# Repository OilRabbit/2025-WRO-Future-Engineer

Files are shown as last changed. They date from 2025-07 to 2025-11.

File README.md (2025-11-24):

# Welcome to the GitHub Repository of Team Evo1ution for 2025 WRO Future Engineering 

## Links

[About Our Team](#about-our-team)

[Documentation](documentation/WROFEReport.pdf)

[Meeting Agenda & Minutes](https://docs.google.com/document/d/1UcRYFaWVR6Crpbr7qZHQyp-bxXoaFOH1-K7Gqp4DvTU/edit?usp=sharing)

[Pictures and Practice Videos](picsNveds)

[Practice Videos](picsNveds/videos_link.md)

[Our Code](https://github.com/OilRabbit/2025-WRO-Future-Engineer/tree/Gen-6.0_ESP32/main)

[Wiring Diagram](https://github.com/OilRabbit/2025-WRO-Future-Engineer/tree/Gen-6.0_ESP32/wiring)

## About Our Team

Our team is comprised of five Po Leung Kuk Tang Yuk Tien College alumni, each a former Robotics Team chairperson. Through years of competitions and training, we forged strong friendships and a shared passion for robotics. As avid World Robot Olympiad (WRO) supporters, we were excited to learn that the Future Engineer category age limit increased to 22 in 2025. In January, during a casual meetup, we resolved to reunite and compete together once again.

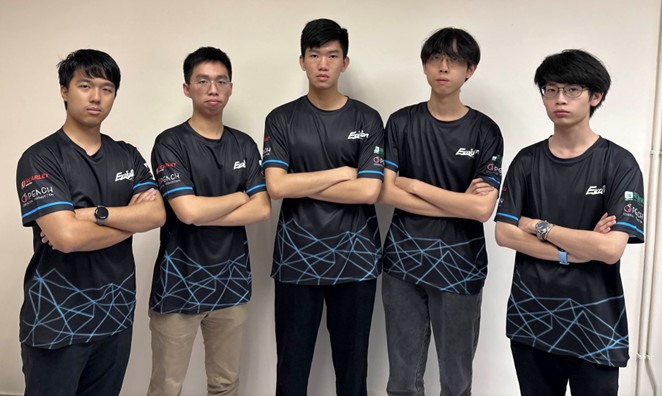
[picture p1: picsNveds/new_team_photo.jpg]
team_photo

### Members' Introductions (from left to right)

#### Rex Sin (Participant) – Age 19
Rex is studying Computer Science in Australia, but remains fully engaged in our team via video conferencing. He leads strategy design, debugging, and solution development, produces and uploads our YouTube videos, and co-ordinates this report. He began robotics at age 12 and won the U.S. Robot Parade world championship represent-ing Hong Kong, later earning numerous local competition awards.

#### Donald Tong (Participant) – Age 19
Donald, a Civil and Environmental Engineering student and PLKTYTC Robotics Team coach, develops core li-braries and functions, fine-tunes robot behavior, and conducts extensive operational tests, such as evaluating var-ied object placements. He and Rex Sin earned second place in the 2024 WRO Hong Kong Senior Robomission selection, and he previously placed second in the 2019 international Beach Rescue and Salvage Robot contests.

#### Elwin Li (Coach) – Age 22
Elwin is an MPhil Physics student who previously coached the PLKTYTC Robotics Team and Physics Olympiad class. With expertise in physics, mathematics, and programming, he contributes to university research on gravita-tional waves. In our team, he directs meeting planning, goal setting, task assignment, sponsorship coordination, hardware procurement, and, most critically, programming strategy. Elwin also competed in the 2021 Robocon Hong Kong Contest and served as a judge for the 2024 WRO Hong Kong Future Engineer selection.

#### Harrison Tsang (Participant) – Age 20
Studying Artificial Intelligence: Systems and Technologies, Harrison coaches the PLKTYTC Robotics Team and leads our robot construction and primary program development. While preparing concurrently for the 2025 Ro-bocon Hong Kong Contest, he brought experience as the 2021 WRO Hong Kong Senior RoboMission champion and multiple world-title winner in international robotics that year.

#### Harold Cheung (Supporter) – Age 23
Harold is a final-year Aeronautical and Aviation Engineering student and former PLKTYTC Robotics Team coach, specializing in mechanical design and robot structures. In our team, he delivers vehicle fundamentals training, oversees mechanical design, advises on sensor integration and strategy, and assists with component procure-ment. A motorsport enthusiast and amateur go-kart racer, Harold has competed alongside Elwin in robotics con-tests for over ten years, even leveraging insights from his personal kart to inform our robot’s design.

----

## Our design for the Hong Kong Regional Copetition
During the WRO Hong Kong Regional Competition, we selected the MATRIX Mini R4 controller and some of its official motors and sensors. We believed that they should work well together to maximise the overall performance as they are all MATRIX electrical components. The chassis was built with LEGO and MATRIX components assisted with screwes to hold the electrical components. 

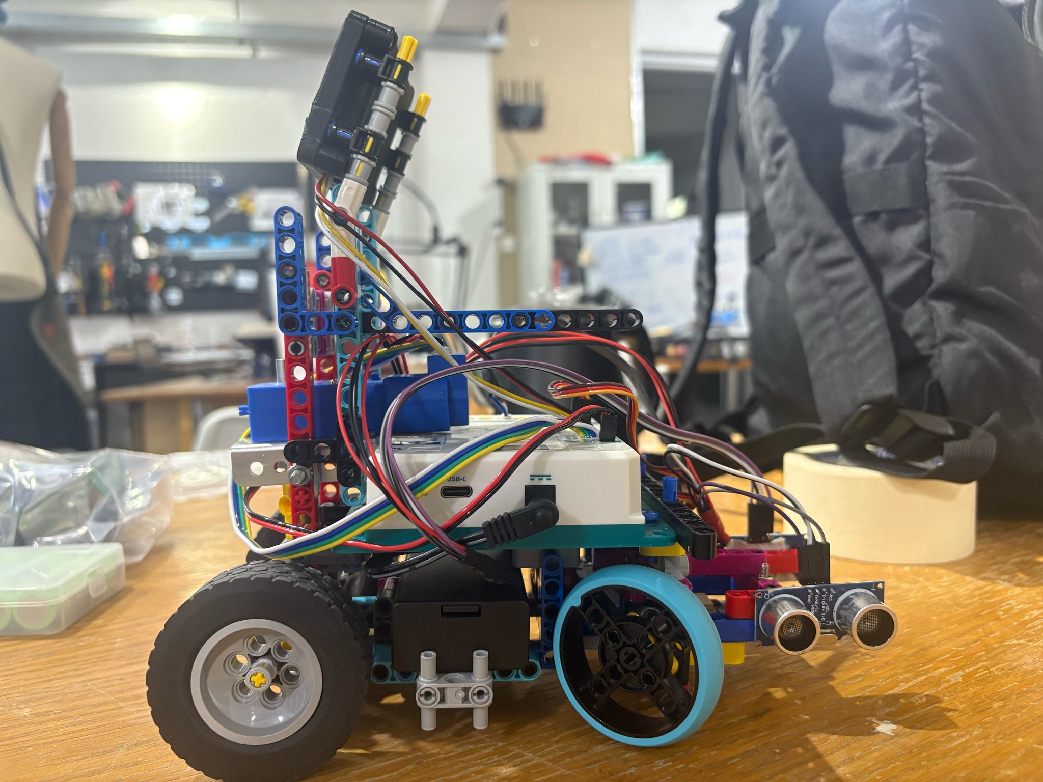
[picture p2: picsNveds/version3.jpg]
version3


However, we found that the MATRIX controller has a high latency when handling multiple tasks and an unstable IMU sensor. These problems increased the diffculty of tuning the program because of errors caused by them. Thus, we decided to replace those electrical components with better models.

----

## Our current design

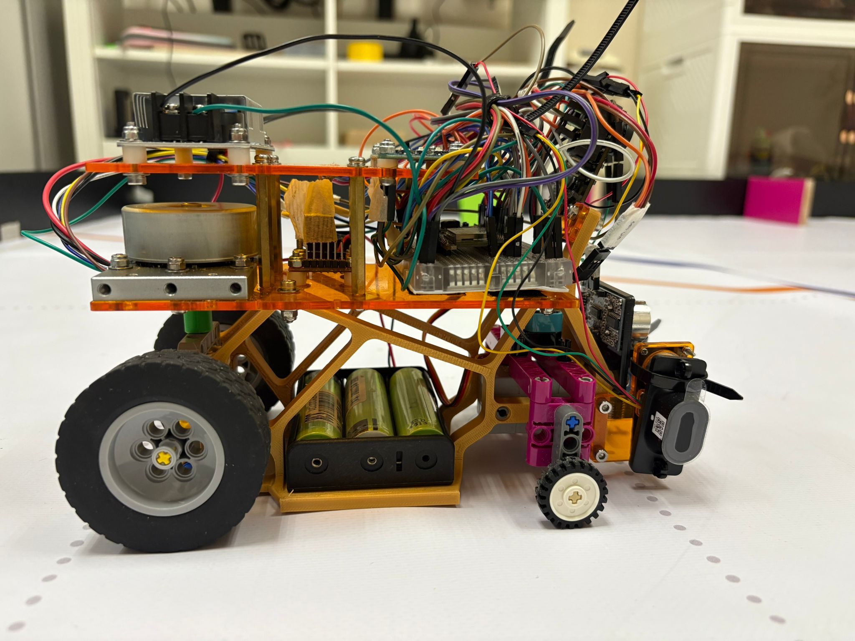
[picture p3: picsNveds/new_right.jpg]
new_right


After doing some research about controllers that are often used in such competitions, we decided to separate into two sub-teams to work on EV3 and ESP32 separately. Despite the fact that EV3 has several limitations on both hardware and software, we still gave it a try, as we are all familiar with it. As a result, it has much higher stability than the MATRIX robot. However, the problem of gyro drift is critical, and the robot does not move fast enough. Meanwhile, we found that the ESP32 features multi-threading and powerful computing. From the result of testing the processing power of the ESP32 by replacing the MATRIX controller with the ESP32 while other electronic components remain the same, it showed its excellent performance and stability. Thus, we decided to work further on ESP32.

To further enhance performance, we replaced the MATRIX motor with the BM50 brushless motor with an encoder for the drive, which in-creases speed. It offers additional stability, acting like a gyroscope while in operation, and features a built-in en-coder for precise power control. Regarding the problematic sensors, we changed a better IMU (ICM-20948) and camera (PixyCam2.1). It is worth mentioning that the ultrasonic sensors were replaced by ToF sensors due to the fast measuring rate and high accuracy of ToF sensors.

----

## How do we work together
As a current college students, we need to balance our studies, works, and the preperation for this competition. Although our spare time do not collide much, we spent as much time as possible working on this project. Even though sometimes we need to work alone. By the way, thank to our coach and supporter for taking time from their busy schedule to come to our working place to give advises. We used GitHub to share code and log our work. We communicate through a WhatsApp group and have a short call with Rex regularly to update him about the condition for the documentations and strategy designs.

----

## What we learnt
* Slip angle optimisation is unnecessary for our small robot, the Ackermann effect is minimal, though we demonstrated a simple LEGO implementation regardless.
* A differential is essential: it significantly smooths turning at low speeds despite a slight reduction in straight‐line velocity.
* A shorter wheelbase enhances turning fluidity.
* A wider track during turns, greater spacing between front wheels than rear, improves cornering smooth-ness (we omitted this due to chassis‐width constraints).
* Lightweight wheels markedly increase top speed more than reducing overall vehicle mass.
* Smaller wheel diameters boost manoeuvrability.
* A low centre of mass enhances stability.
* An onboard gyro provides precise heading data and lap counting.
* Storing pillar colours in an array on the first detection enables faster reaction on subsequent passes.
* Reducing camera resolution (where feasible) increases frame rate and responsiveness.

----

## Conclusion
This is a really challenging project as this is our first time using those hardware and there are so many things need to learn for this. We enjoy the process of searching through the field we love and learning something new. We believe that what we learnt from this competition is more valuable than the result.

----

## Special thanks
Our sponsors:

| [Peach Creatice Production](https://www.peachcp.com/wp/) | [TURNED-E!](https://www.turned-e.com/) | [Scarlet Racing](https://www.facebook.com/scarlet.racing.hk/?locale=zh_HK) | Electronic Slash |
| --- | --- | --- | --- |
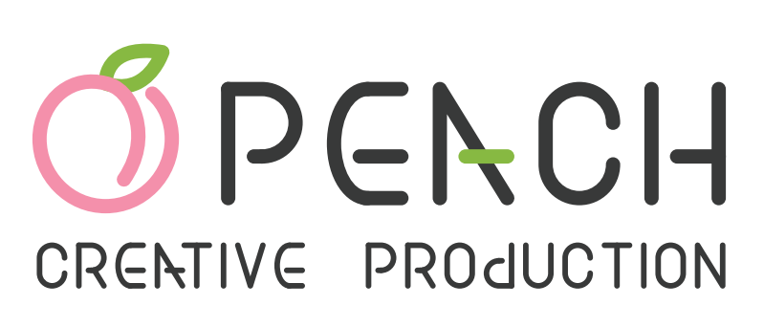
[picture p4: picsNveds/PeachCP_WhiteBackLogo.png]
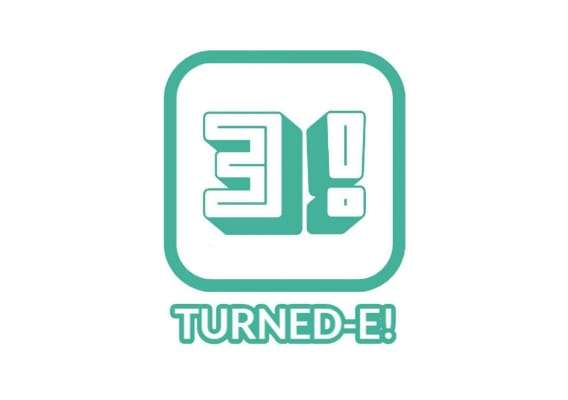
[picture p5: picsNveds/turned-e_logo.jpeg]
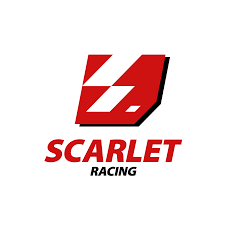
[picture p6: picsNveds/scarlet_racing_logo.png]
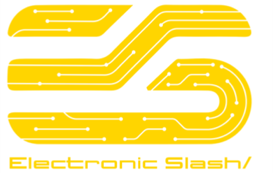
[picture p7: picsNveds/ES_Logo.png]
|||||

Also thank to our parents, coach and supporter for supporting us to explore the field we love.

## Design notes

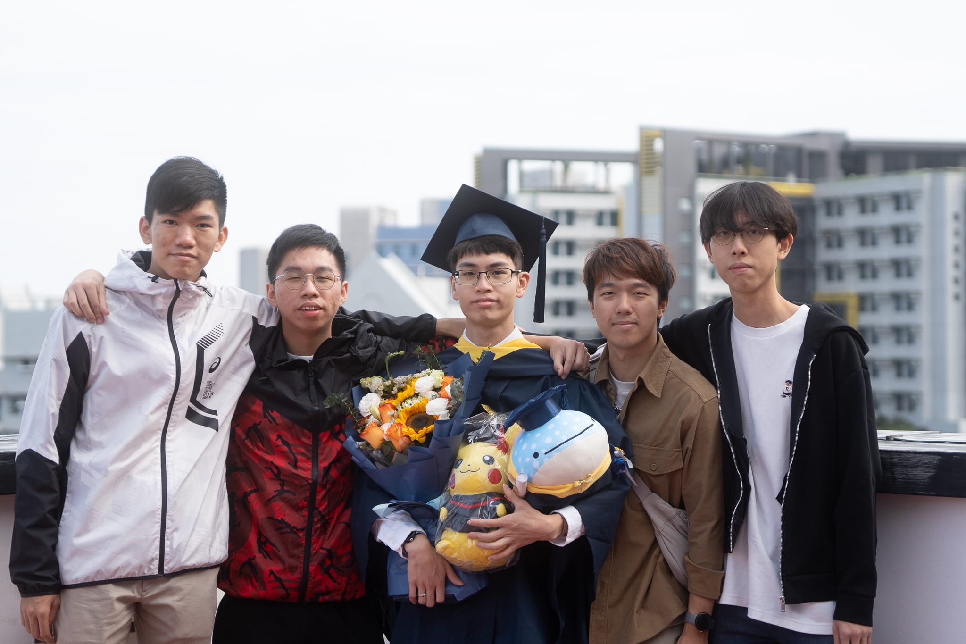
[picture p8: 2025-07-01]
picsNveds/team_photo13.jpeg

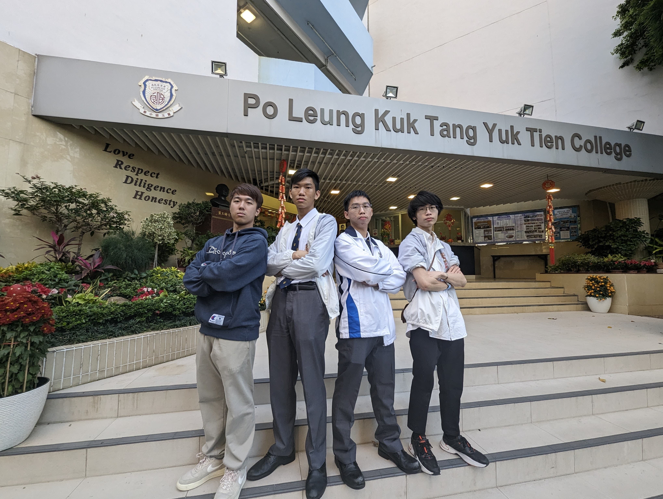
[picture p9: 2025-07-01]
picsNveds/team_photo7.jpeg

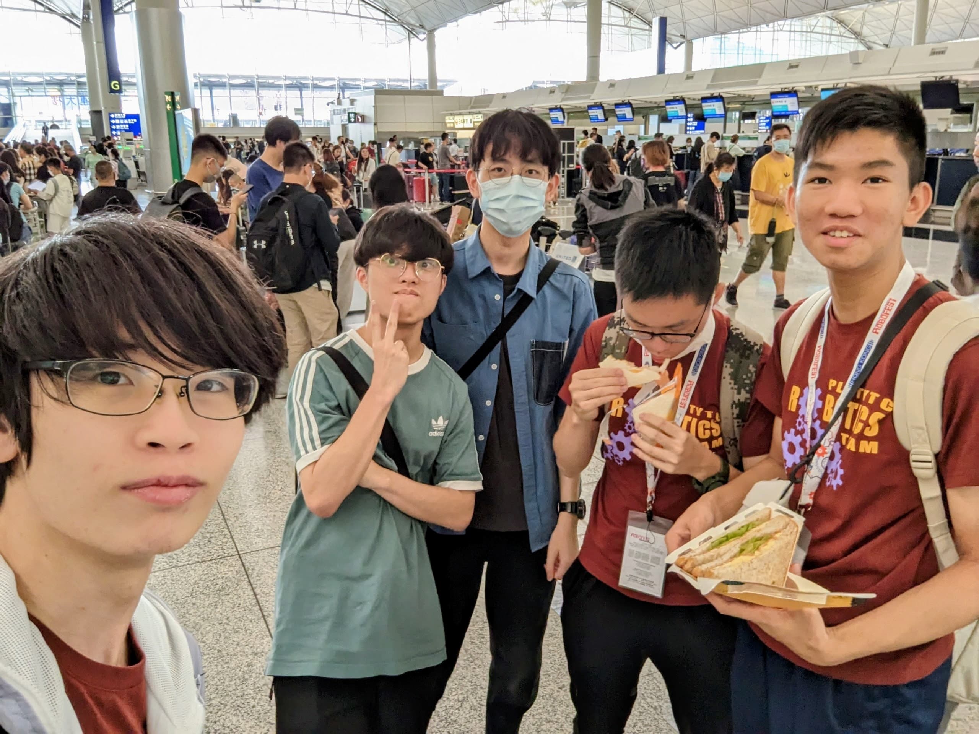
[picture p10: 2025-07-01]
picsNveds/team_photo15.jpeg

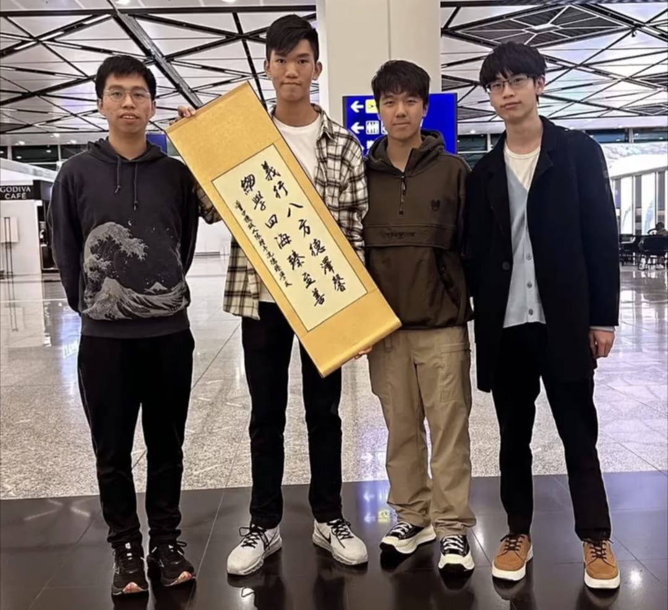
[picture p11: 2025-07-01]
picsNveds/team_photo12.jpeg

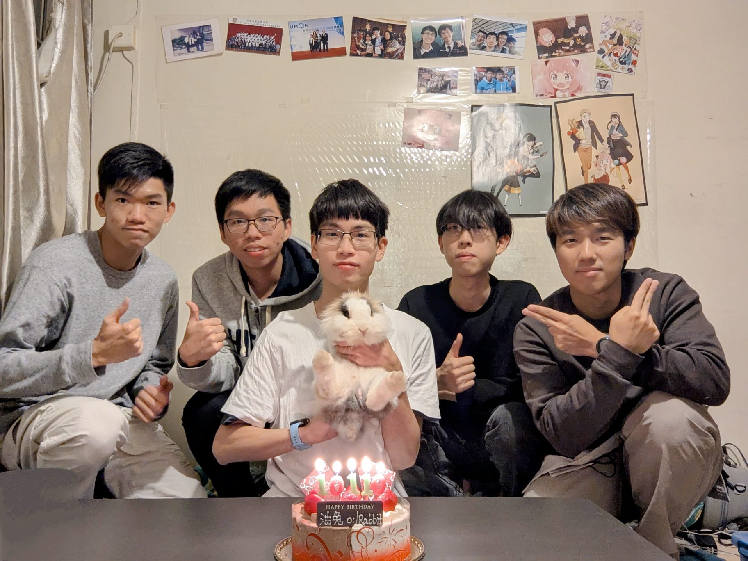
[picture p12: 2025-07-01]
picsNveds/team_photo2.jpeg

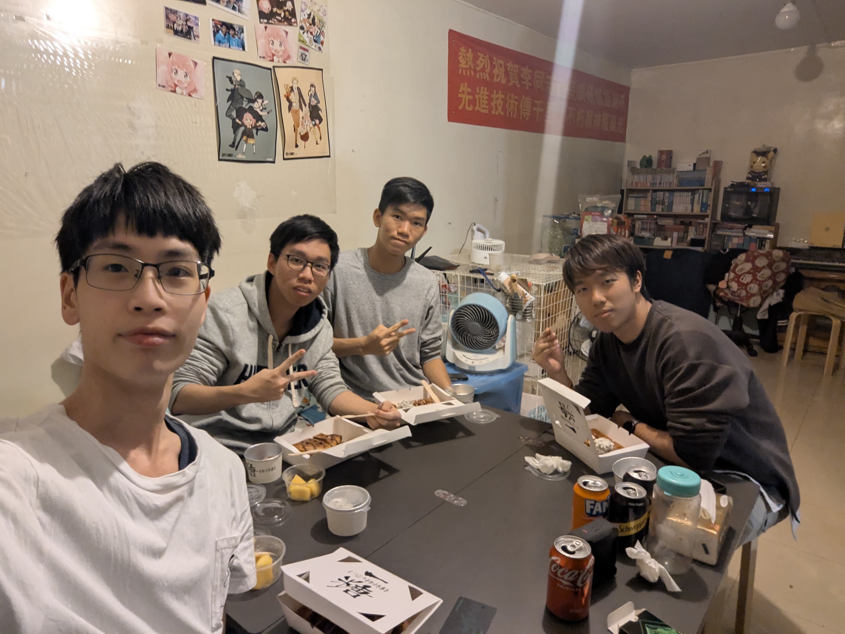
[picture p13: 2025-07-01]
picsNveds/team_photo5.jpeg

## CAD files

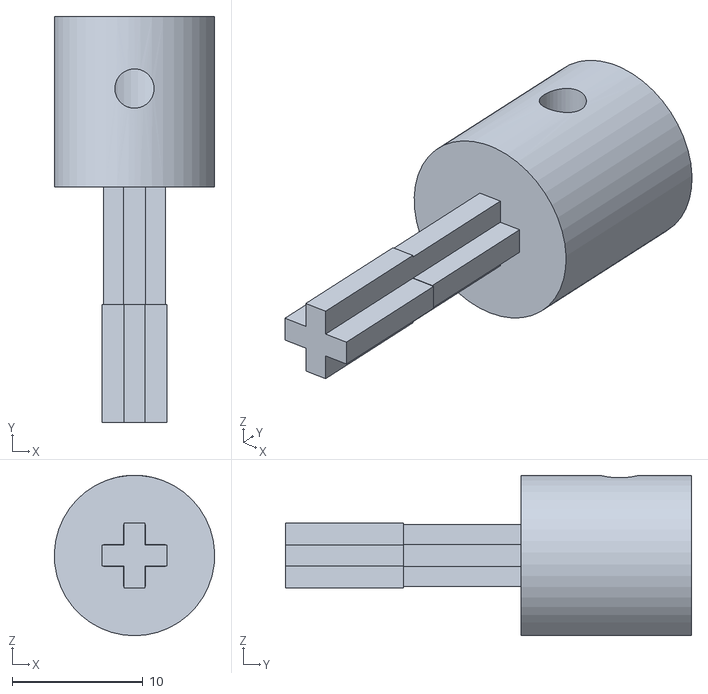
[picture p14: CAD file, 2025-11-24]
picsNveds/3DPrint/6.25_3.85_1.STL
12.2 x 31.0 x 12.2

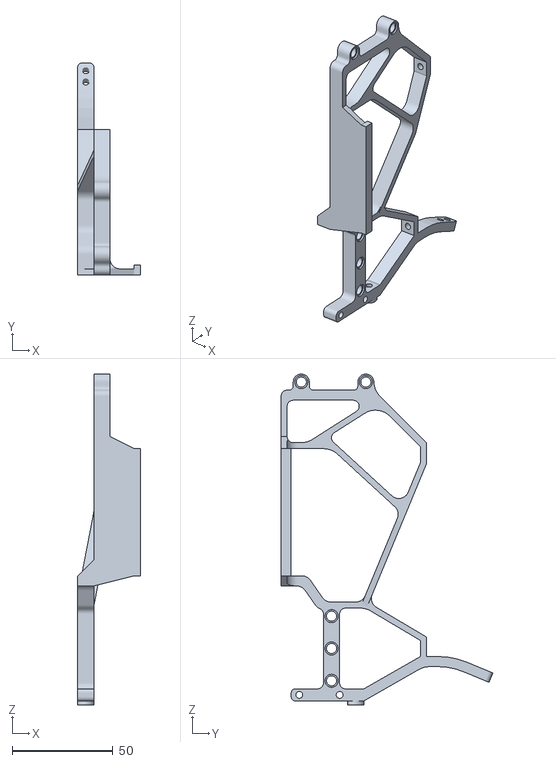
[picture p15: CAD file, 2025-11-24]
picsNveds/3DPrint/3dp_base_frame.STL
31.0 x 104.9 x 164.0

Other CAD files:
picsNveds/3DPrint/Mirror3dp_base_frame.STL

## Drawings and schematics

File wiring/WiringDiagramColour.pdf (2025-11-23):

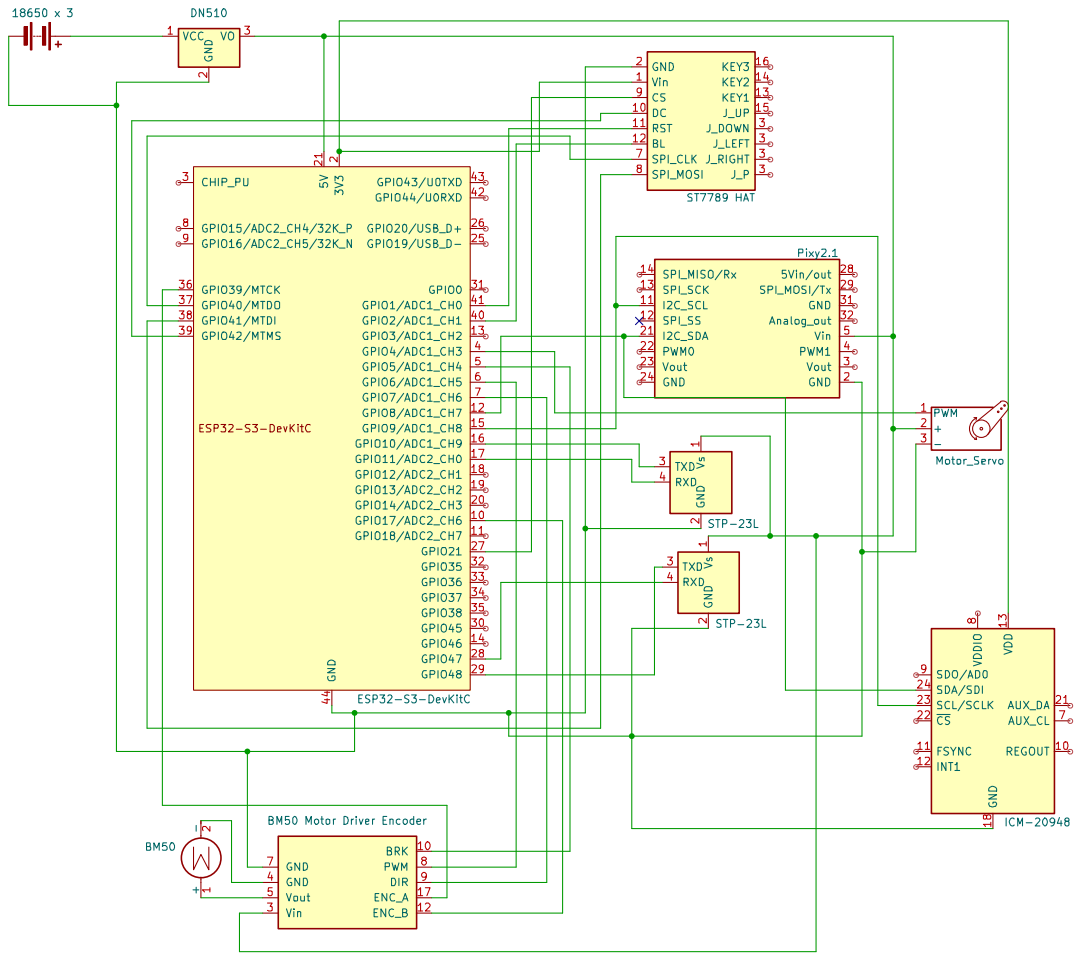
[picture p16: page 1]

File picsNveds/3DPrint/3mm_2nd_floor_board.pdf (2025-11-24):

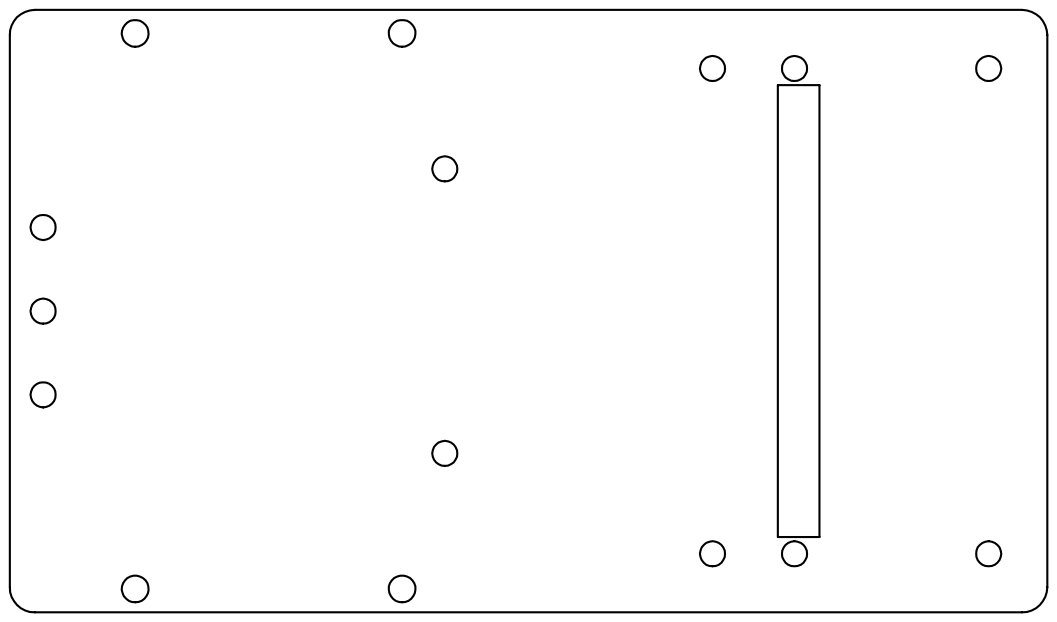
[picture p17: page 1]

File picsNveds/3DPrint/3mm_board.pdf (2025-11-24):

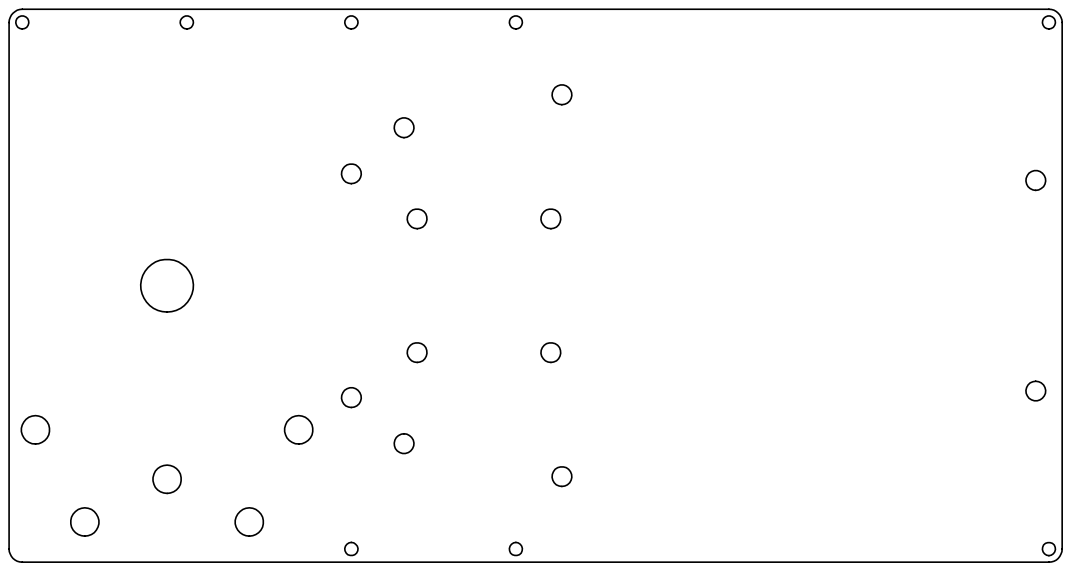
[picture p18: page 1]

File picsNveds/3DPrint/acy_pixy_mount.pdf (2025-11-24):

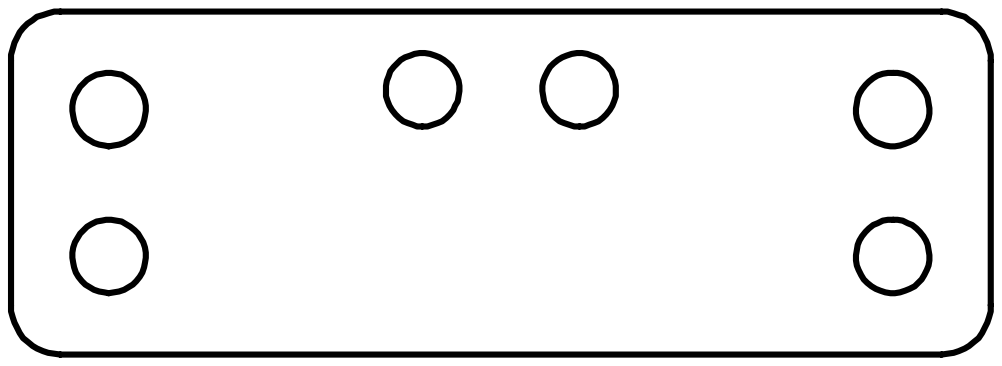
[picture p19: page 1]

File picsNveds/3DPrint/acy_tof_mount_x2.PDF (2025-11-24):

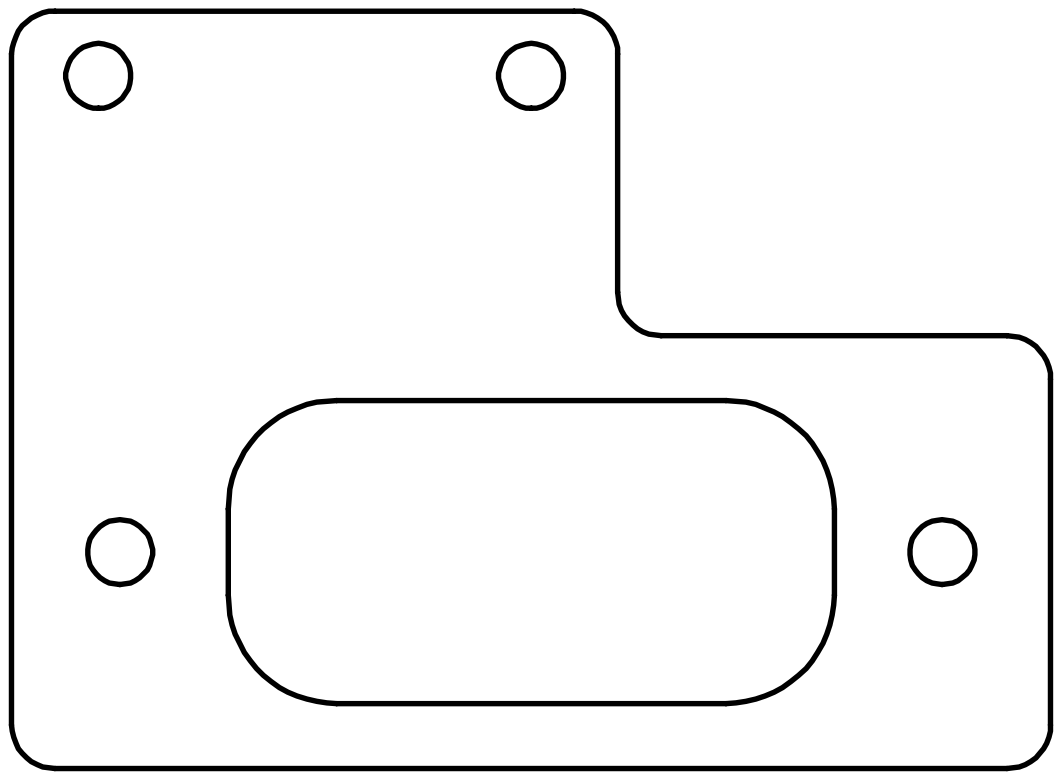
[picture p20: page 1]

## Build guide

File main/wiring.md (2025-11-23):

### SPI LCD (ST7789 HAT)

* SCLK (1st row, pin 12) → **GPIO40**
* MOSI (1st row, pin 10) → **GPIO41**
* CS (2nd row, pin 12) → **GPIO21**
* DC (2nd row, pin 11) → **GPIO42**
* RST (1st row, pin 7) → **GPIO1**
* BL (2nd row, pin 9) → **GPIO2** (drive HIGH to turn backlight on)
* VCC (1st row, pin 1) → 3V3
* GND (2nd row, pin 3) → GND

### HAT Buttons & Joystick  *(active-LOW, use `INPUT_PULLUP`)*

* KEY1 (2nd row, pin 20) → **GPIO12**
* KEY2 (2nd row, pin 19) → **GPIO13**
* KEY3 (2nd row, pin 18) → **GPIO14**
(UNUSED) * JOY UP → **GPIO15**
(UNUSED) * JOY DOWN → **GPIO16**
(UNUSED) * JOY LEFT → **GPIO17**
(UNUSED) * JOY RIGHT → **GPIO18**
(UNUSED) * JOY PRESS → **GPIO11**

### Qwiic IMU (ICM-20948, I²C @ 3.3 V), share with Pixy2

* SDA → **GPIO8** (purple)
* SCL → **GPIO9**
* VCC → 3V3, GND → GND

### Pixy 2.1 (UART)

* SDA (3rd row, pin 1) → **GPIO8**
* SCL (5th row, pin 1) → **GPIO9**
* VCC (1st row, pin 2) → 5V
* GND (3rd row, pin 2) → GND

### ToF  *(power both from 5 V)*

* ToF 1 (Left): **TX → GPIO10**, **RX → GPIO11**
* ToF 2 (Left): **TX → GPIO48**, **RX → GPIO47**

### BM50 brushless motor with encoder
* Brake (blue) → **GPIO5**
* PWM (green) → **GPIO6**
* Dir (brown) → **GPIO7**
* ENCPinA → **GPIO39** (yellow)
* ENCPinB → **GPIO17** (white)

### Servo

* Signal (orang) → **GPIO4** (LEDC @ 50 Hz)
* Power servo (red) from 5–6 V (not 3V3); GND (brown) common

### HC-SR04 x2  *(power both from 5 V; **ECHO must be level-shifted to 3.3 V**)*

* (UNUSED) Sensor A (Left): **TRIG → GPIO10**, **ECHO → GPIO11** (through resistor divider)
* (UNUSED) Sensor B (Right): **TRIG → GPIO47**, **ECHO → **GPIO48** (through resistor divider)
* (UNUSED) Sensor C (Front): **TRIG → GPIO15**, **ECHO → **GPIO16** (through resistor divider)

#### Notes / gotchas

* **Do not use**: GPIO0 (BOOT strap), **GPIO19/20** (USB D−/D+), **GPIO45/46** (input-only; avoid for TRIG/PWM).

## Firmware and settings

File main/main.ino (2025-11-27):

#include "main.h"

// Create threads for different tasks
TaskHandle_t blinkledThread = NULL;
TaskHandle_t displayThread = NULL;
TaskHandle_t ToF1Thread = NULL;
TaskHandle_t ToF2Thread = NULL;
TaskHandle_t IMUThread = NULL;
TaskHandle_t SteeringThread = NULL;
TaskHandle_t MotorEncThread = NULL;
TaskHandle_t Pixy2Thread = NULL;
TaskHandle_t OC1Thread = NULL;
TaskHandle_t OC2Thread = NULL;

void setup() {
  // Initialization
  motor_preinit_safe();
  Serial.begin(115200);
  tft.init();
  tft.displayln(30, 0, 2, "Initializing...", TFT_WHITE, true);
  
  // Showing the init status of each components
  int line_iter = 2;
  #ifdef FENZY_MODE
    tft.displayLeftln(line_iter++, 2, "LED Init:", TFT_WHITE, false);
    tft.displayLeftln(line_iter++, 2, "Clk Init:", TFT_WHITE, false);
    tft.displayLeftln(line_iter++, 2, "Ser Init:", TFT_WHITE, false);
    tft.displayLeftln(line_iter++, 2, "Tf1 Init:", TFT_WHITE, false);
    tft.displayLeftln(line_iter++, 2, "Tf2 Init:", TFT_WHITE, false);
    tft.displayLeftln(line_iter++, 2, "Btn Init:", TFT_WHITE, false);
    tft.displayLeftln(line_iter++, 2, "Imu Init:", TFT_WHITE, false);
    tft.displayLeftln(line_iter++, 2, "Str Init:", TFT_WHITE, false);
    tft.displayLeftln(line_iter++, 2, "Pxy Init:", TFT_WHITE, false);
    tft.displayLeftln(line_iter++, 2, "Mtr Init:", TFT_WHITE, false);
  #endif
  
  line_iter = 2;

  led_init();
  #ifdef FENZY_MODE
    delay(100);
    tft.displayRightln(line_iter++, 2, "Done", TFT_GREEN, false);
  #endif
  internalClock.start();

  #ifdef FENZY_MODE
    delay(100);
    tft.displayRightln(line_iter++, 2, "Done", TFT_GREEN, false);
  #endif

  Serial.begin(115200);
  #ifdef FENZY_MODE
    delay(100);
    tft.displayRightln(line_iter++, 2, "Done", TFT_GREEN, false);
  #endif

  tofInit();
  #ifdef FENZY_MODE
    delay(100);
    tft.displayRightln(line_iter++, 2, "Done", TFT_GREEN, false);
    tft.displayRightln(line_iter++, 2, "Done", TFT_GREEN, false);
  #endif

  btn_init();
  #ifdef FENZY_MODE
    delay(100);
    tft.displayRightln(line_iter++, 2, "Done", TFT_GREEN, false);
  #endif

  imu_init();
  #ifdef FENZY_MODE
    delay(100);
    tft.displayRightln(line_iter++, 2, "Done", TFT_GREEN, false);
  #endif

  steeringInit();
  #ifdef FENZY_MODE
    delay(100);
    tft.displayRightln(line_iter++, 2, "Done", TFT_GREEN, false);
  #endif

  motor_init();
  #ifdef FENZY_MODE
    delay(100);
    tft.displayRightln(line_iter++, 2, "Done", TFT_GREEN, false);
  #endif

  Serial.println("Init Pixy2...");
  Wire.begin(PIXY2_SDA, PIXY2_SCL, 100000);
  Wire.setClock(400000);
  Serial.println("Init Pixy2...");
  pixy.init();
  #ifdef FENZY_MODE
    delay(100);
    tft.displayRightln(line_iter++, 2, "Done", TFT_GREEN, false);
  #endif

  xTaskCreatePinnedToCore(
    blinkledLED_test,         // Task function
    "Blink LED",              // Task name
    10000,                    // Stack size (bytes)
    NULL,                     // Parameters
    1,                        // Priority
    &blinkledThread,          // Task handle
    1                         // Core 1
  );

  xTaskCreatePinnedToCore(
    getToF1Distloop,          // Task function
    "Get ToF 1 Distance",     // Task name
    10000,                    // Stack size (bytes)
    NULL,                     // Parameters
    1,                        // Priority
    &ToF1Thread,              // Task handle
    0                         // Core 0
  );

  xTaskCreatePinnedToCore(
    getToF2Distloop,          // Task function
    "Get ToF 2 Distance",     // Task name
    10000,                    // Stack size (bytes)
    NULL,                     // Parameters
    1,                        // Priority
    &ToF2Thread,              // Task handle
    0                         // Core 0
  );

  xTaskCreatePinnedToCore(
    getYPRloop,               // Task function
    "Get IMU Data",           // Task name
    10000,                    // Stack size (bytes)
    NULL,                     // Parameters
    1,                        // Priority
    &IMUThread,               // Task handle
    1                         // Core 1
  );

  xTaskCreatePinnedToCore(
    steeringloop,             // Task function
    "Steering",               // Task name
    10000,                    // Stack size (bytes)
    NULL,                     // Parameters
    1,                        // Priority
    &SteeringThread,          // Task handle
    1                         // Core 1
  );

  xTaskCreatePinnedToCore(
    motor_encloop,            // Task function
    "Motor Encoder",          // Task name
    10000,                    // Stack size (bytes)
    NULL,                     // Parameters
    1,                        // Priority
    &MotorEncThread,          // Task handle
    1                         // Core 1
  );

  xTaskCreatePinnedToCore(
    getNearestBlkloop,        // Task function
    "Pixy2",                  // Task name
    10000,                    // Stack size (bytes)
    NULL,                     // Parameters
    1,                        // Priority
    &Pixy2Thread,             // Task handle
    1                         // Core 1
  );

  #ifdef FENZY_MODE
    delay(500);
  #else
    delay(300);
  #endif

  tft.clear();

  xTaskCreatePinnedToCore(
    displayData,              // Task function
    "Display info",           // Task name
    10000,                    // Stack size (bytes)
    NULL,                     // Parameters
    1,                        // Priority
    &displayThread,           // Task handle
    1                         // Core 1
  );

  // xTaskCreatePinnedToCore(
  //   OC1main,                  // Task function
  //   "OC1",                    // Task name
  //   10000,                    // Stack size (bytes)
  //   NULL,                     // Parameters
  //   1,                        // Priority
  //   &OC1Thread,               // Task handle
  //   1                         // Core 1
  // );

  xTaskCreatePinnedToCore(
    OC2main,                  // Task function
    "OC2",                    // Task name
    10000,                    // Stack size (bytes)
    NULL,                     // Parameters
    1,                        // Priority
    &OC2Thread,               // Task handle
    1                         // Core 1
  );
}

void loop() {
  // Nothing as the threads are running independently
  while (Serial2.available()) Serial.write(Serial2.read());
}

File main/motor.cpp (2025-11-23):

#include "HardwareSerial.h"
#include "Motor.h"

#include "motor.h"
#include <math.h>
#include <driver/pulse_cnt.h> 

// Global variables for the BM50 motor
volatile long MOTOR_ENCODER_COUNT = 0;
long          MOTOR_ENCODER_VALUE = 0;

// PWM polarity (true = active-low)
const bool PWM_ACTIVE_LOW = true;

static pcnt_unit_handle_t    s_pcnt_unit = nullptr;
static pcnt_channel_handle_t s_chan_a    = nullptr;
static pcnt_channel_handle_t s_chan_b    = nullptr;

/**
 * @brief Helper functions to convert percentage to duty cycle
 * @param p; int; percentage
 */
static inline uint32_t duty_from_percent(int p) {
  int mag = abs(p);
  if (mag > 100) mag = 100;
  uint32_t d = (uint32_t)mag * PWM_MAX_DUTY / 100;
  if (PWM_ACTIVE_LOW) d = PWM_MAX_DUTY - d;
  return d;
}

/**
 * @brief Helper functions to apply motor direction to pwm
 * @param p; int; motor direction
 */
static inline void apply_pwm_dir(int p) {
  digitalWrite(PIN_M_DIR, (p >= 0) ? HIGH : LOW);
  digitalWrite(PIN_M_BRAKE, HIGH);                      // release brake
  ledcWrite(PIN_M_PWM, duty_from_percent(p));
}

/**
 * @brief PCNT encoder setup function
 */
static void encoder_pcnt_init() {
  pcnt_unit_config_t unit_cfg = {};
  unit_cfg.low_limit  = INT16_MIN;
  unit_cfg.high_limit = INT16_MAX;
  ESP_ERROR_CHECK(pcnt_new_unit(&unit_cfg, &s_pcnt_unit));

  // Glitch filter to suppress EMI/bounce (tune 200..2000 ns)
  pcnt_glitch_filter_config_t filt_cfg = {};
  filt_cfg.max_glitch_ns = 1000;
  ESP_ERROR_CHECK(pcnt_unit_set_glitch_filter(s_pcnt_unit, &filt_cfg));

  // Channel A: edge=A, level=B
  pcnt_chan_config_t ch_a_cfg = {};
  ch_a_cfg.edge_gpio_num  = PIN_ENC_A;
  ch_a_cfg.level_gpio_num = PIN_ENC_B;
  ESP_ERROR_CHECK(pcnt_new_channel(s_pcnt_unit, &ch_a_cfg, &s_chan_a));

  // Channel B: edge=B, level=A
  pcnt_chan_config_t ch_b_cfg = {};
  ch_b_cfg.edge_gpio_num  = PIN_ENC_B;
  ch_b_cfg.level_gpio_num = PIN_ENC_A;
  ESP_ERROR_CHECK(pcnt_new_channel(s_pcnt_unit, &ch_b_cfg, &s_chan_b));

  // Quadrature actions (standard mapping)
  ESP_ERROR_CHECK(pcnt_channel_set_edge_action(
    s_chan_a, PCNT_CHANNEL_EDGE_ACTION_INCREASE, PCNT_CHANNEL_EDGE_ACTION_DECREASE));
  ESP_ERROR_CHECK(pcnt_channel_set_level_action(
    s_chan_a, PCNT_CHANNEL_LEVEL_ACTION_KEEP, PCNT_CHANNEL_LEVEL_ACTION_INVERSE));

  ESP_ERROR_CHECK(pcnt_channel_set_edge_action(
    s_chan_b, PCNT_CHANNEL_EDGE_ACTION_INCREASE, PCNT_CHANNEL_EDGE_ACTION_DECREASE));
  ESP_ERROR_CHECK(pcnt_channel_set_level_action(
    s_chan_b, PCNT_CHANNEL_LEVEL_ACTION_INVERSE, PCNT_CHANNEL_LEVEL_ACTION_KEEP));

  ESP_ERROR_CHECK(pcnt_unit_enable(s_pcnt_unit));
  ESP_ERROR_CHECK(pcnt_unit_clear_count(s_pcnt_unit));
  ESP_ERROR_CHECK(pcnt_unit_start(s_pcnt_unit));
}

/**
 * @brief Init function for the motor
 */
void motor_init() {
  // Keep brake asserted until PWM ready
  digitalWrite(PIN_M_BRAKE, LOW);

  ledcAttach(PIN_M_PWM, PWM_FREQ_HZ, PWM_BITS);
  ledcWrite(PIN_M_PWM, PWM_ACTIVE_LOW ? PWM_MAX_DUTY : 0); // OFF

  pinMode(PIN_M_DIR, OUTPUT);
  digitalWrite(PIN_M_DIR, LOW);

  pinMode(PIN_M_BRAKE, OUTPUT);

  // Encoder pins & PCNT
  pinMode(PIN_ENC_A, INPUT_PULLUP);
  pinMode(PIN_ENC_B, INPUT_PULLUP);
  encoder_pcnt_init();

  MOTOR_ENCODER_COUNT = 0;
  MOTOR_ENCODER_VALUE = 0;
}

/**
 * @brief Read the encoder value from the encoder sensor to update the global variable
 */
void read_encoder() {
  int hw = 0;
  if (s_pcnt_unit) pcnt_unit_get_count(s_pcnt_unit, &hw);
  MOTOR_ENCODER_COUNT = (long)hw;
  MOTOR_ENCODER_VALUE = (long)hw;
}

/**
 * @brief Reset the encoder value 
 */
void reset_encoder() {
  if (s_pcnt_unit) pcnt_unit_clear_count(s_pcnt_unit);
  MOTOR_ENCODER_COUNT = 0;
  MOTOR_ENCODER_VALUE = 0;
}

/**
 * @brief Move the motor with the input power
 * @param speed_percentage; int; Speed percentage (-100% ~ 100%) (Negative as moving backward)
 */
void motor_move(int speed_percentage) {
  if (speed_percentage > 100)  speed_percentage = 100;
  if (speed_percentage < -100) speed_percentage = -100;
  apply_pwm_dir(speed_percentage);
}

/**
 * @brief Stop the motor with the input method
 * @param brake_method; BRAKE_TYPE; Method to brake the motor. BRAKE: stop the motor by providing a force to it. COAST: stop the motor by without providing
 * an external force
 */
void motor_stop(BRAKE_TYPE brake_method) {
  // PWM off
  ledcWrite(PIN_M_PWM, PWM_ACTIVE_LOW ? PWM_MAX_DUTY : 0);
  if (brake_method == BRAKE) digitalWrite(PIN_M_BRAKE, LOW);   // active brake
  else                       digitalWrite(PIN_M_BRAKE, HIGH);  // coast
}

/**
 * @brief Blocking move by degrees (sign of deg = direction)
 * @param deg; int; encoder value to be moved
 * @param speed_percentage; int; Speed percentage (-100% ~ 100%) (Negative as moving backward)
 * @param brake_method; BRAKE_TYPE; Method to brake the motor. BRAKE: stop the motor by providing a force to it. COAST: stop the motor by without providing
 */
void motor_on_degree(int deg, int speed_percentage, BRAKE_TYPE brake_method) {
  if (deg == 0 || speed_percentage == 0) { motor_stop(brake_method); return; }

  // target ticks (abs)
  long target_ticks = (long)(( (double)ENCODER_CPR * (double)abs(deg) ) / 360.0);
  if (target_ticks == 0) target_ticks = 1;

  // start reference
  read_encoder();
  long start = MOTOR_ENCODER_VALUE;

  // direction from sign of deg
  int dir = (deg >= 0) ? 1 : -1;
  motor_move(dir * abs(speed_percentage));

  const uint32_t timeout_ms = 10000; // safety
  uint32_t t0 = millis();
  for (;;) {
    read_encoder();
    long progressed = labs(MOTOR_ENCODER_VALUE - start);
    if (progressed >= target_ticks) break;
    if ((uint32_t)(millis() - t0) > timeout_ms) break;
    vTaskDelay(pdMS_TO_TICKS(2));
  }

  motor_stop(brake_method);
}
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

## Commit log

2025-04-04 Display done
    Add lots of useful display functions. Also show the time and battery level at the moon
2025-04-06 Pish
    - Modified all the display functions:
    we can make the refresh rate of the moon as large as possible now
    - Added huskylens functions:
    You can now read from the huskylens and also read the nearest object detected
    - Added gyro functions:
    You can now get values from the gyro. The one with Kalman filter is not accurate. Don't use it.
2025-04-12 Added laser average function
2025-04-12 OC 1 using filter written
2025-04-19 Add median filter
2025-05-04 pish
    Tired
2025-05-05 OC1 Done!!!!!!!!!!
    Now OC 1 is done. The smart car is using ultrasonic sensors. It will do PID to get close to the inner wall. Time of the run is also shown.
    Users do not need to reboot the robot to restart the run. They just need to press the down button again
    [OC1.cpp, main.ino]
2025-05-17 OC2 not finish
    [huskylens.xlsx]
2025-05-20 OC2 object detector half-ly done
    [huskylens.xlsx]
2025-05-22 Forgot to push this
    [huskylens.xlsx]
2025-05-25 OC2 pillar avoiding system done
    [OC1.cpp, OC2.cpp]
2025-05-27 pish
    OC2 is basically done, but need some fine tuning
    [huskylens.xlsx]
2025-06-03 Not yet finished refractoring
    [huskylens.xlsx]
2025-06-03 OC1 changed
    target angle changed but the ultrasonic sensor sucks
2025-06-10 Revert "OC1 changed"
    This reverts commit cf545549620e6d3618bd8606b3d238219c64f099.
    [OC1.cpp, main.ino]
2025-06-16 OC2 with color sensor version not done
2025-06-28 IMU functions update
2025-08-15 Can blink led now
2025-09-11 ESP32 Saikou
    Done the following using ESP32:
    - Verified the FreeRTOS multi-threading method on the ESP32
    - Tested and finished the LED library for the built-in LED on the ESP32
    - Tested and finished the tft library for the 1.3" LCD hat
    - Finished the library for displaying data and information on the LCD monitor
    - Tested and halfly finished the library for the ultrasonic sensor with the NewPing library
2025-10-02 Mostly done, but Pixy2 SPI not working
    [buttons.cpp, main.ino, motor.cpp]
2025-11-04 Done motor and new workflow for OC1
2025-11-05 New function for OC1 (fixed path)
    [OC1.cpp, buttons.cpp]
2025-11-07 OC2 without parking lot 80% finished
    [pixy2.xlsx]
2025-11-07 Turning threshold table
    [pixy2.xlsx]
2025-11-14 Update tof wiring
2025-11-17 Fix conflicts. OC2 pixy function tested
    OC2 Pixy function not working for extreme case atm
    [OC2.cpp]
2025-11-20 New function, 90%
    [pixy2.xlsx]
2025-11-22 fix timer
2025-11-23 Wiring diagram
2025-11-23 Add wiring diagram
    [Untitled.kicad_sch]
2025-11-23 Update README with project details and team info
    Added links to code repository and wiring diagram, updated team member introductions, and revised project design sections.
2025-11-24 OC1 changed
    [pixy2.xlsx]
